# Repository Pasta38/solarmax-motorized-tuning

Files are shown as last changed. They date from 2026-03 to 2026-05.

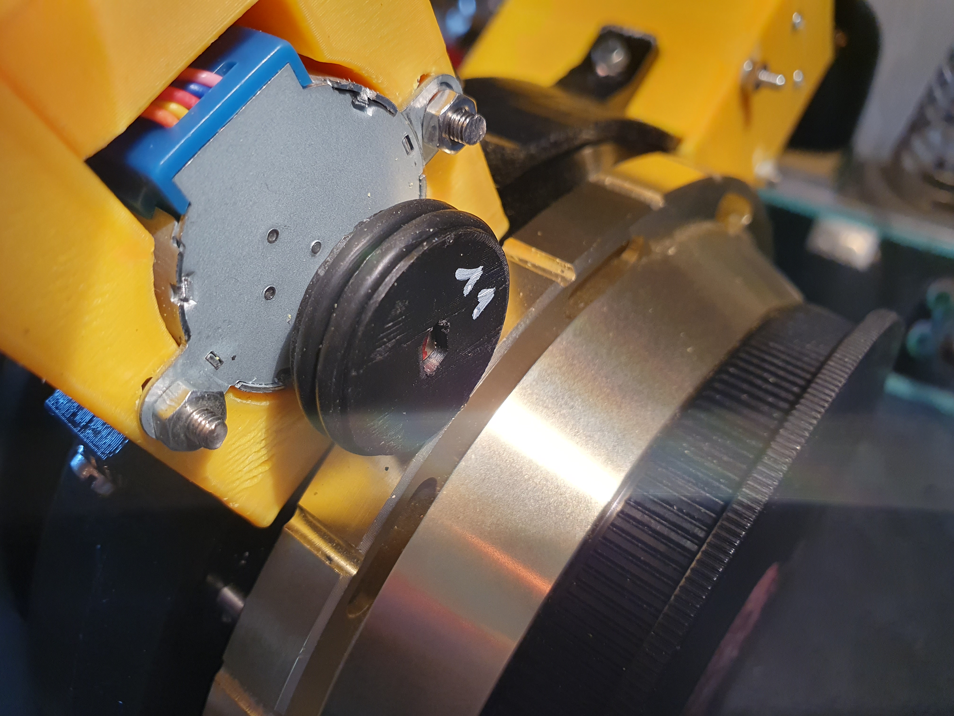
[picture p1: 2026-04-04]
docs/photos/Mecanique/SudNord_Ver1-2.jpg

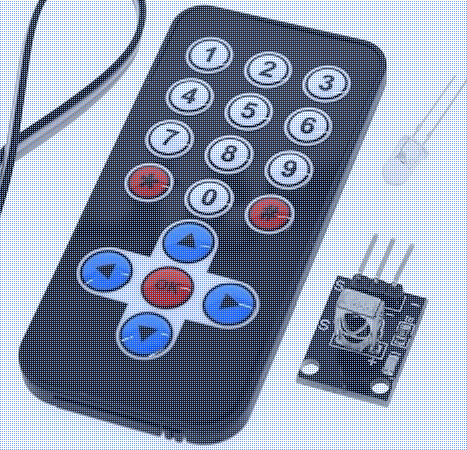
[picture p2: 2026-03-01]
docs/photos/Electronique/Telecommande et recepteur IR.png

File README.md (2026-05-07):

# solarmax-motorized-tuning
Motorized tuning system for Solarmax III 90 double stack telescope

# Système de réglage motorisé pour Solarmax III 90 Double Stack

## Présentation

Ce projet propose un **système de motorisation des réglages** pour une lunette solaire Solarmax III 90 en configuration double stack.

L’objectif est de permettre un réglage **précis, reproductible et confortable** des bagues d’accord, sans manipulation directe sur l’instrument.
Le système est entièrement conçu dans une logique **DIY / open hardware**, avec :

* Électronique basée sur Arduino
* PCB personnalisés
* Pièces mécaniques imprimables en 3D
* Câblage modulaire

Il est particulièrement adapté aux astrophotographes et observateurs solaires souhaitant automatiser leur réglage sans modification permanente de l’instrument.

---

## Fonctionnalités principales

* Commande à distance via télécommande infrarouge
* 4 moteurs indépendants
* Réglage fin et répétable
* Câblage modulaire RJ12
* Boîtier compact
* Pièces 100% imprimables en 3D
* Composants économiques et faciles à trouver

---

## Architecture du système

### Vue d’ensemble

Le système se compose de trois sous-ensembles principaux :

1. Électronique de contrôle
2. Cartes adaptatrices moteurs
3. Ensemble mécanique

---

## Électronique

### Carte principale

Carte conçue avec **KiCad** et fabriquée chez **JLCPCB**.

#### Fonctions

* Support Arduino Nano
* Pilotage de 4 moteurs pas-à-pas
* Réception infrarouge
* Distribution alimentation
* Connectique RJ12 pour moteurs

#### Caractéristiques

* PCB double couche
* Composants traversants (facilité d’assemblage)
* Conception compacte

---

### Composants principaux

| Composant | Rôle |
| --- | --- |
| Arduino Nano | Contrôleur principal |
| 2 × ULN2003AN | Drivers moteurs |
| 2 × 28BYJ-48 5V  | Moteurs pas-à-pas |
| 2 × A4988 | Drivers moteurs |
| 2 × NEMA 17 | Moteurs pas-à-pas |
| Récepteur IR | Interface télécommande |
| Régulateur 5V | 9v vers 5v LM7805 |
| Connecteurs RJ12 | Liaison moteurs |
| JST-XH5 | Connexion côté moteur  |

---

### Cartes adaptatrices RJ12 → JST-XH5

Quatre petites cartes dédiées permettent :

* Conversion RJ12 vers connecteur moteur standard
* Déport des connexions près des moteurs
* Maintenance facilitée

Elles sont volontairement simples pour un assemblage rapide.

---

## Partie mécanique

### Conception

Toutes les pièces mécaniques ont été conçues avec **FreeCAD** et optimisées pour l’impression 3D FDM.

### Éléments fournis

* Boîtier électronique
* Supports moteurs
* Interfaces de fixation sur la lunette (brides)
* Systèmes de maintien des câbles (optionnel)

### Objectifs de conception

* Montage sans modification irréversible de la lunette
* Démontage rapide
* Rigidité suffisante pour réglages fins
* Impression sans supports complexes

---

### Paramètres d’impression recommandés

| Paramètre | Valeur conseillée |
| --- | --- |
| Technologie | FDM |
| Buse | 0.4 mm |
| Hauteur de couche | 0.2 mm |
| Remplissage | 20–30% |
| Matériau | PETG recommandé |

#### Remarques

* PETG pour stabilité thermique
* ABS possible en environnement chaud
* PLA déconseillé en plein soleil

---

## Firmware

Le firmware est conçu pour un **Arduino Nano**.

### Fonctions

* Décodage télécommande infrarouge
* Sélection individuelle des moteurs
* Contrôle pas-à-pas
* Gestion du sens de rotation
* Réglage fin des déplacements

### Dépendances typiques

* IRremote (ou équivalent)
* Librairies stepper Arduino ou implémentation custom

Voir le dossier `/firmware` pour :

* Code source
* Mapping télécommande
* Instructions de compilation

---

## Câblage

### Principe

Chaque moteur est relié via :

Carte principale → RJ12 → Câble → Carte adaptatrice → JST-XH5 → Moteur

### Avantages

* Modularité
* Remplacement rapide
* Longueur de câble adaptable
* Installation propre

---

## Alimentation

### Spécifications

* Tension : 9V DC (pile)
* Courant recommandé : ≥ 2A

---

## Assemblage

### 1. Assemblage électronique

1. Souder les connecteurs sur la carte principale
2. Installer les drivers
3. Ajouter les headers Arduino
4. Flasher le firmware
5. Tester le récepteur IR
6. Tester chaque moteur individuellement

---

### 2. Cartes adaptatrices

1. Souder RJ12 et JST-XH5
2. Vérifier continuité
3. Identifier chaque moteur

---

### 3. Assemblage mécanique

1. Imprimer toutes les pièces STL
2. Monter les moteurs dans leurs supports
3. Installer les supports sur la lunette
4. Monter l’électronique dans le boîtier
5. Installer le câblage

---

## Calibration

Procédure recommandée :

1. Test à vide (sans charge mécanique)
2. Vérification sens de rotation
3. Correction firmware si nécessaire
4. Installation sur la lunette
5. Définition position neutre
6. Tests de réglage fin

---

## Utilisation

1. Mettre sous tension
2. Pointer la télécommande vers le récepteur
3. Sélectionner le moteur
4. Ajuster le réglage

Le mapping des touches est documenté dans le firmware.

---

## Structure du dépôt

```
/hardware
  /kicad-main-board
  /adapter-pcbs

/mechanical
  /freecad
  /stl

/firmware

/docs
  photos
  schémas
  câblage
```

---

## Fabrication

### PCB

* Compatible JLCPCB standard
* 2 couches
* Fichiers Gerber fournis

---

### Impression 3D

Testé sur imprimantes FDM standard.
Aucune contrainte particulière.

---

## Améliorations possibles

* Contrôle Bluetooth ou WiFi
* Intégration ASCOM / INDI
* Écran OLED
* Positions mémorisées
* Drivers silencieux (TMC)
* Version autonome sur batterie
* Capteurs de position

---

## Licence

Licence MIT (modifiable selon votre choix).

---

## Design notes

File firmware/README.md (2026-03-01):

pilotage de 4 moteurs sur Nano avec une telecommande IR

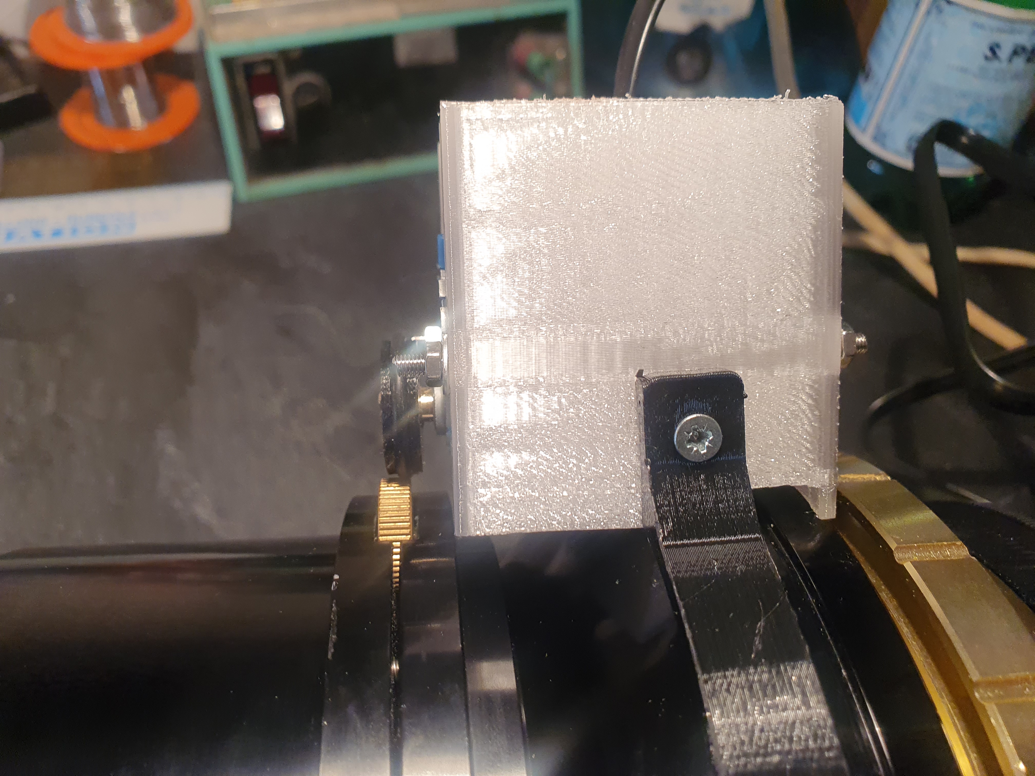
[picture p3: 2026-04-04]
docs/photos/Mecanique/Prototype 2.jpg

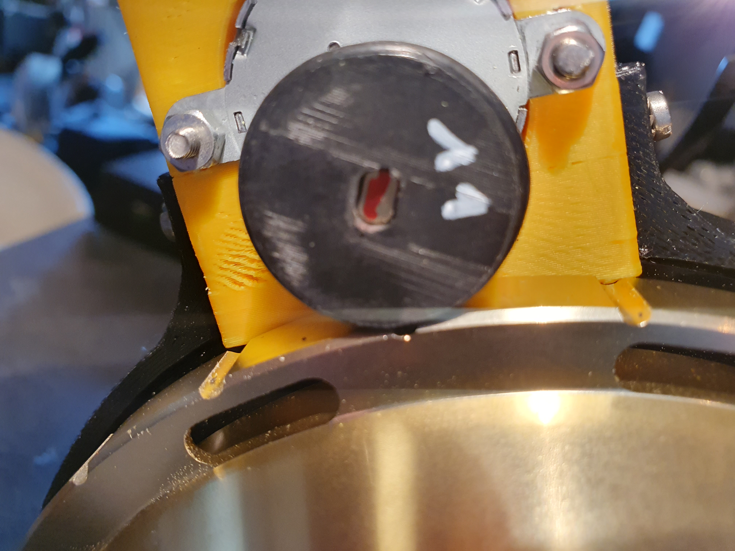
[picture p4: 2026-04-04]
docs/photos/Mecanique/SudNord_Ver1-3.jpg

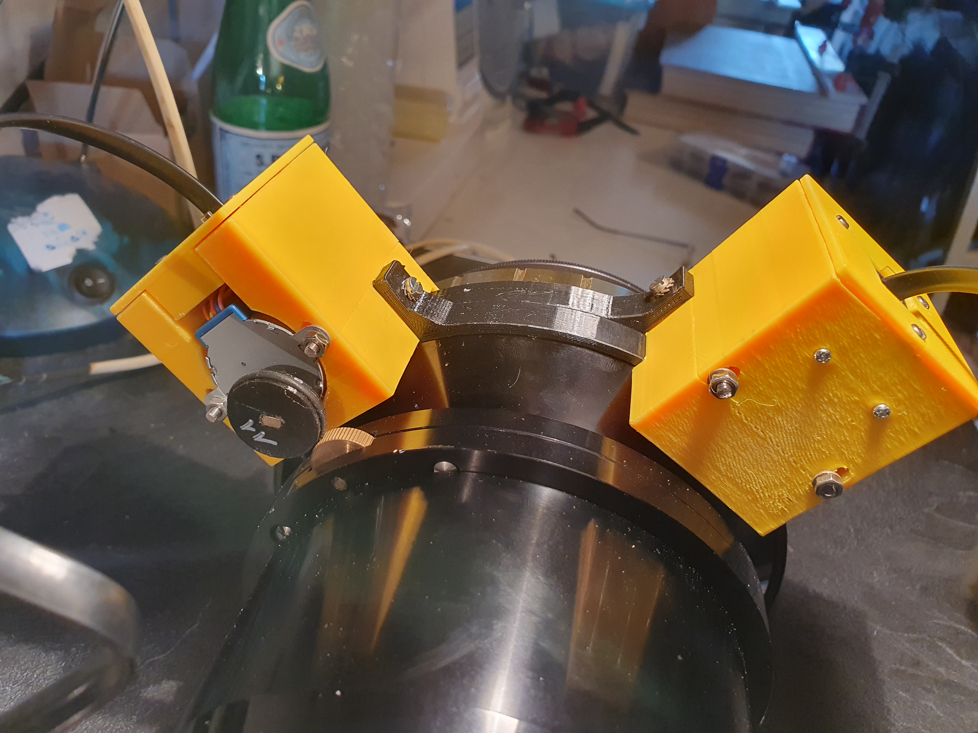
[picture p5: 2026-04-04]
docs/photos/Mecanique/SudNord_Ver1-4.jpg

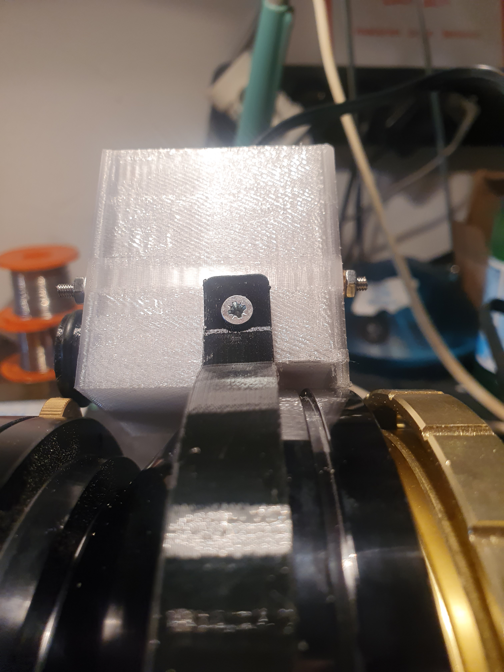
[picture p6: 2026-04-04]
docs/photos/Mecanique/Prototype 3.jpg

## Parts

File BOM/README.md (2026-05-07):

BOM (Bill Of Material) Liste des composants



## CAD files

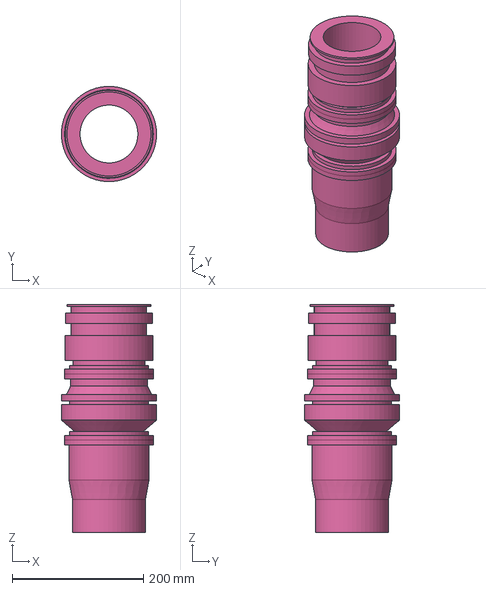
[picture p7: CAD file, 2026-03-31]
mechanical/freecad/Support Moteur & Brides/Coronado-SolamrMaxIII_Model.step
144.9 x 144.9 x 347.0 mm

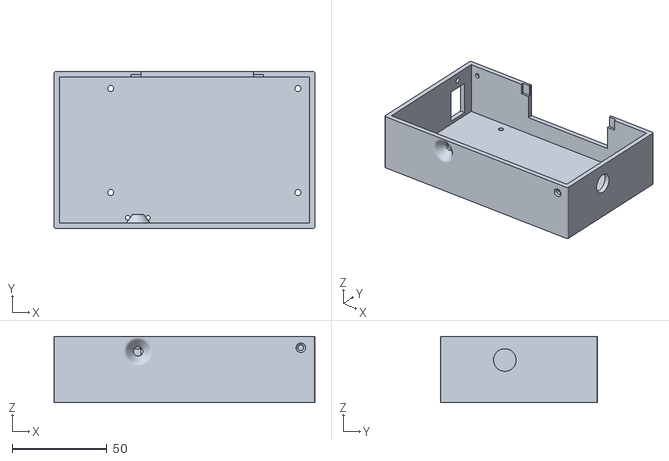
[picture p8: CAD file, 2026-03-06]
mechanical/stl/Boitier/SolarFoc1_box5.stl
138.0 x 83.0 x 35.0

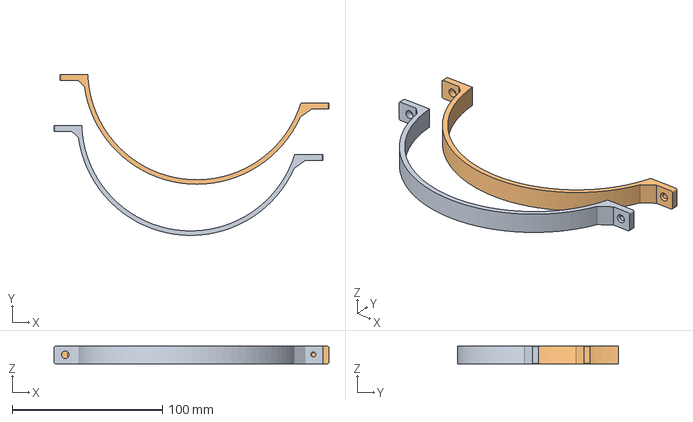
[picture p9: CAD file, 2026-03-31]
mechanical/stl/Brides/demiBrideS3.3mf
183.0 x 107.0 x 11.8 mm
demiBrideS3.stl x 2

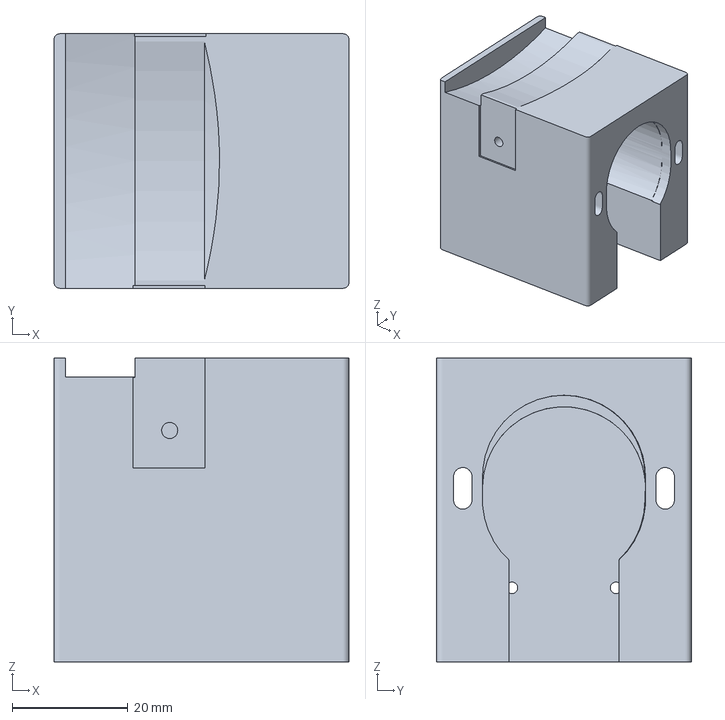
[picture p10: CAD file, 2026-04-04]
mechanical/stl/Supports_Moteurs/Corps3-sud.3mf
51.0 x 44.0 x 52.5 mm

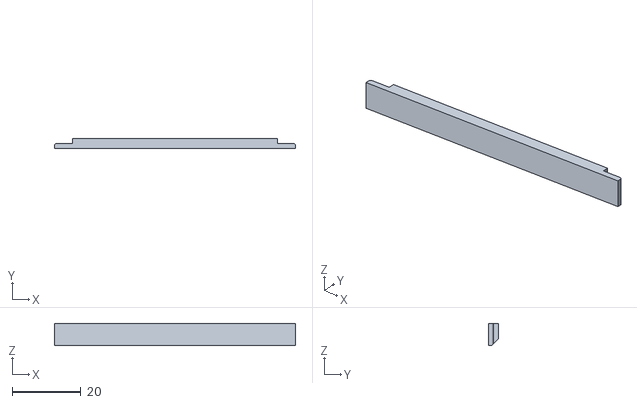
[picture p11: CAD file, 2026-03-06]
mechanical/stl/Boitier/SolarFoc1_Lint5.stl
70.0 x 3.00 x 6.50

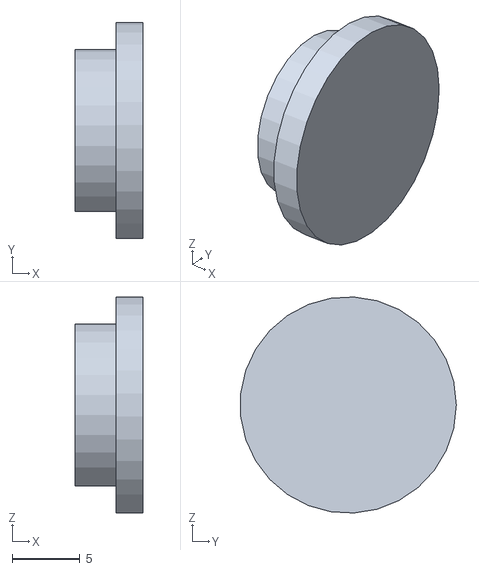
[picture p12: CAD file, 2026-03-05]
mechanical/stl/Boitier/SolarFoc1_SideCov3.stl
5.00 x 16.0 x 16.0

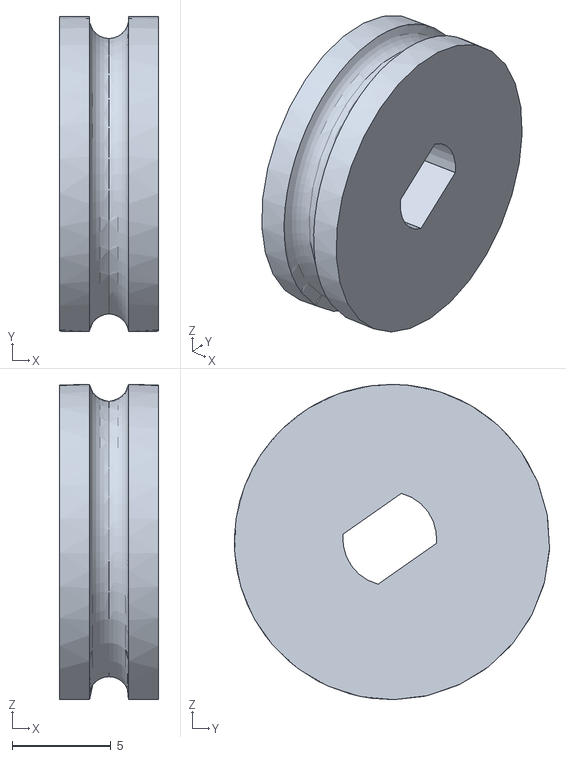
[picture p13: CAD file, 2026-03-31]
mechanical/stl/Supports_Moteurs/Roue.stl
5.00 x 16.0 x 16.0

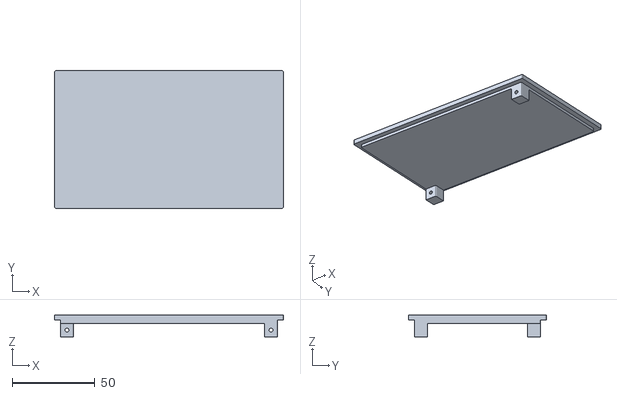
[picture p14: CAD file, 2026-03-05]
mechanical/stl/Boitier/SolarFoc1_TopCov3.stl
138.0 x 83.0 x 13.0

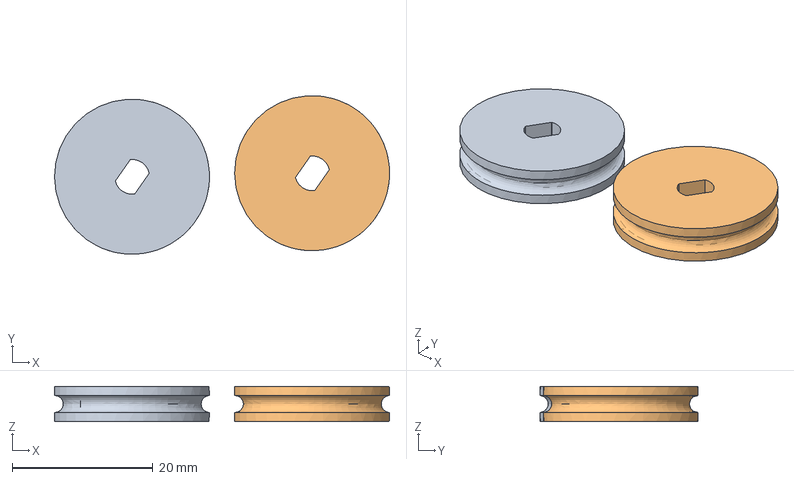
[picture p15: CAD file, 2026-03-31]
mechanical/stl/Supports_Moteurs/Roue_11.3mf
47.6 x 22.5 x 5.00 mm
Roue_11.stl x 2

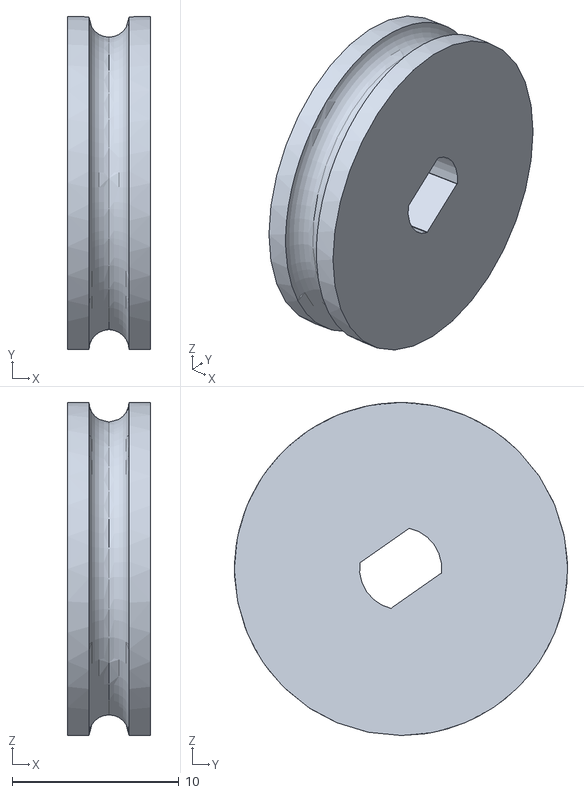
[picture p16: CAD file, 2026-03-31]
mechanical/stl/Supports_Moteurs/Roue_10.stl
5.00 x 20.0 x 20.0

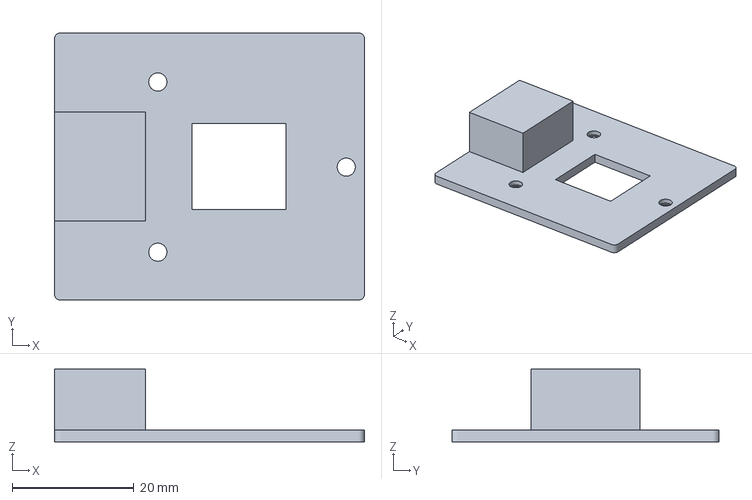
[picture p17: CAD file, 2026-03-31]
mechanical/stl/Supports_Moteurs/Top3.3mf
51.0 x 44.0 x 12.0 mm

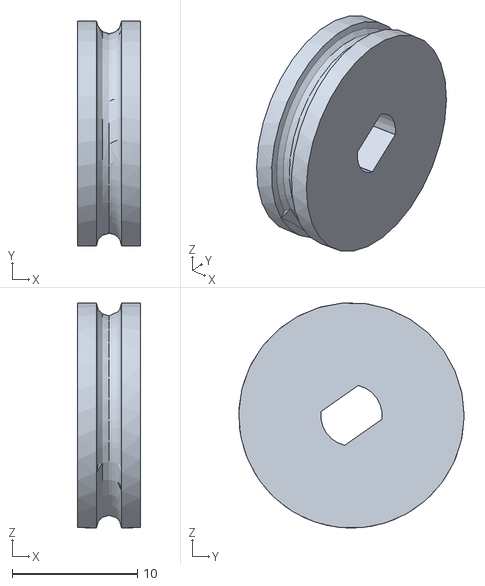
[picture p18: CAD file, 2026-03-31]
mechanical/stl/Supports_Moteurs/Roue_9.stl
5.00 x 18.0 x 18.0

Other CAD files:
mechanical/stl/Supports_Moteurs/Corps1-nord.3mf
mechanical/stl/Brides/demiBrideS3.stl
mechanical/stl/Supports_Moteurs/Corps1-nord.stl
mechanical/stl/Supports_Moteurs/Corps3-sud.stl
mechanical/stl/Supports_Moteurs/Roue_11.stl
mechanical/stl/Supports_Moteurs/Top3.stl

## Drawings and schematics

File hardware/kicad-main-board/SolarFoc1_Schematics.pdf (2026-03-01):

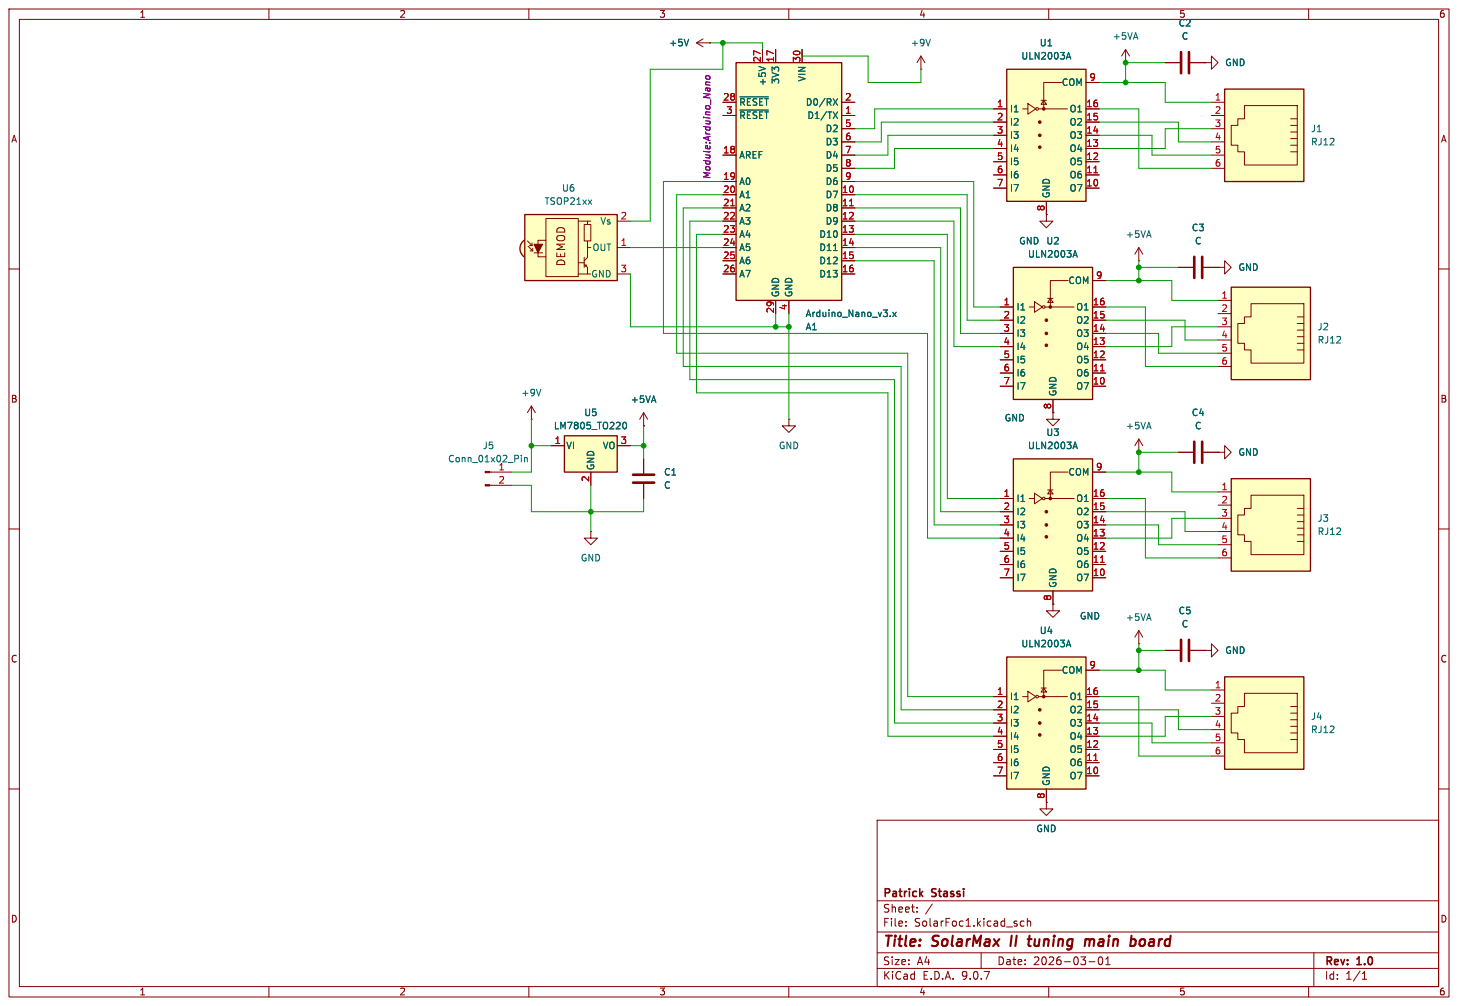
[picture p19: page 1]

Id: 1/1 Title: SolarMax II tuning main board

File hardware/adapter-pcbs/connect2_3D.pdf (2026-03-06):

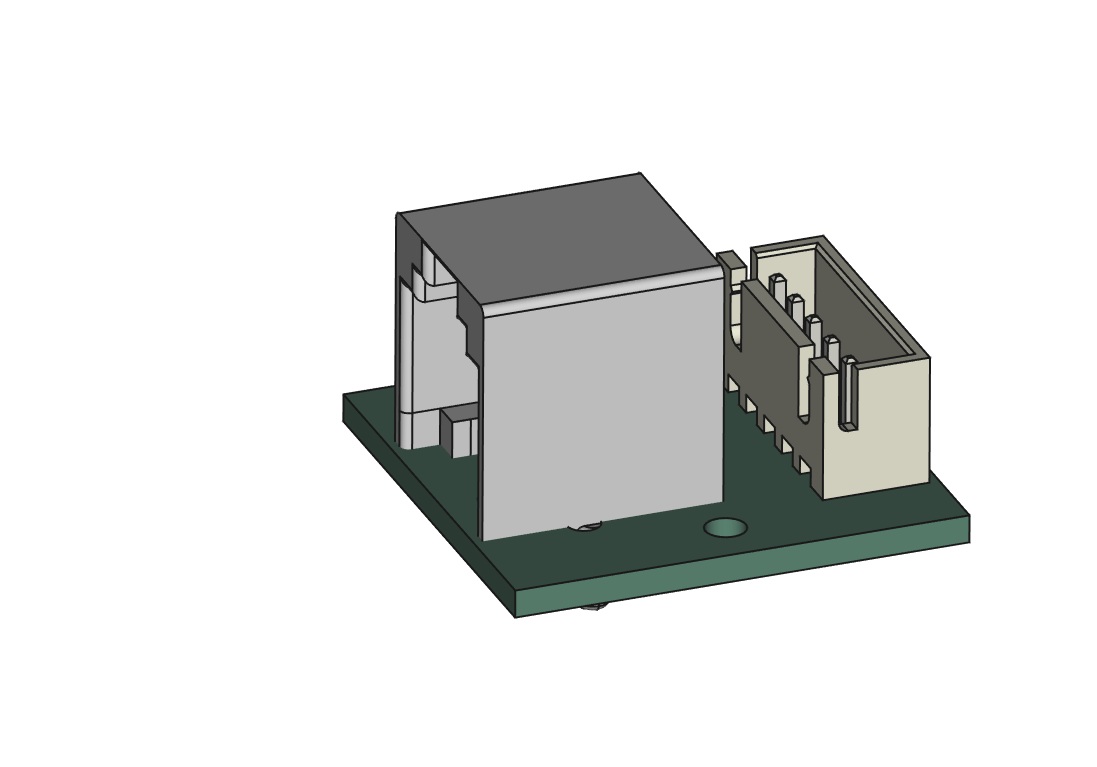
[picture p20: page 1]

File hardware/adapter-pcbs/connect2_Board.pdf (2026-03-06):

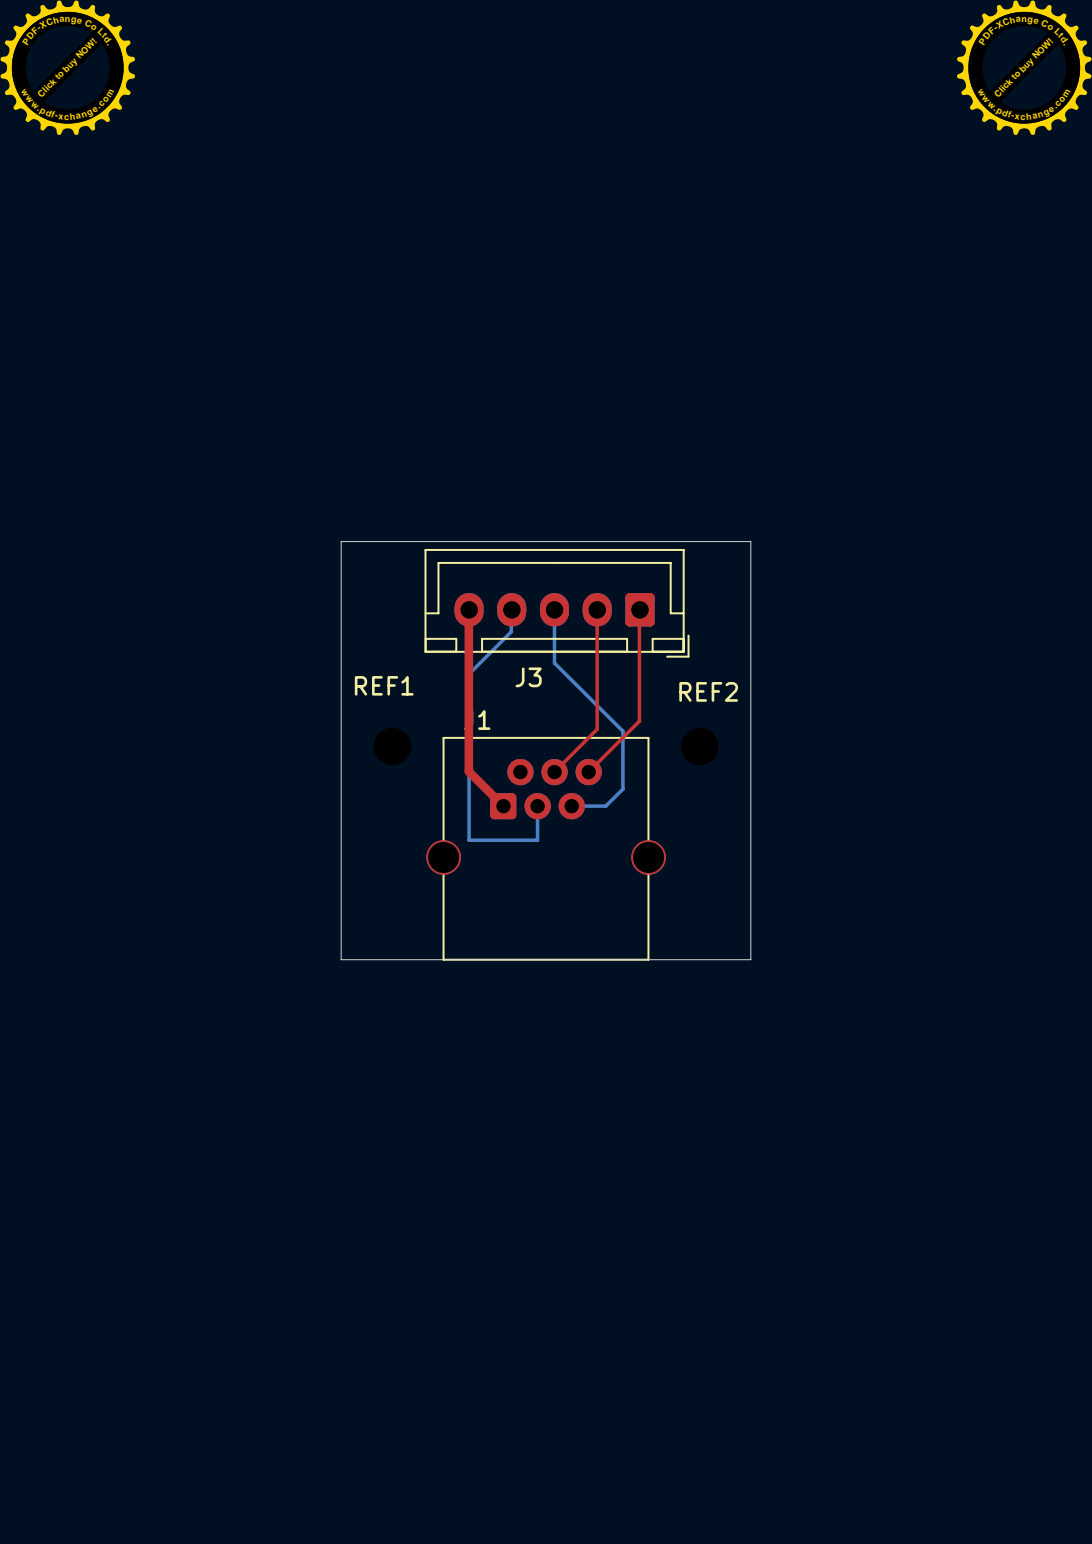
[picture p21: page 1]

PDF-XChange Co Ltd.

Click to buy NOW!

www.pdf-xchange.com

www.pdf-xchange.com (https://www.pdf-xchange.com/buy-now)

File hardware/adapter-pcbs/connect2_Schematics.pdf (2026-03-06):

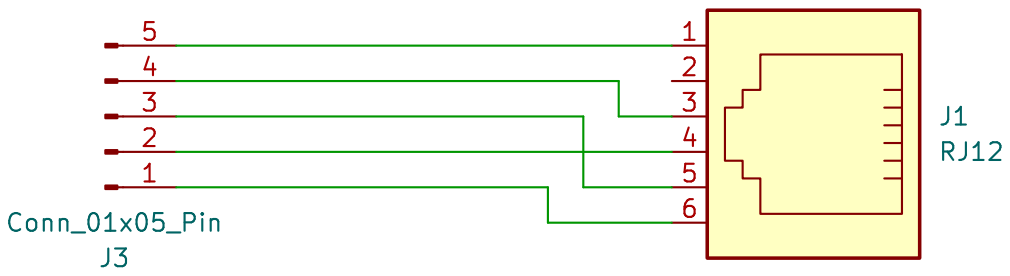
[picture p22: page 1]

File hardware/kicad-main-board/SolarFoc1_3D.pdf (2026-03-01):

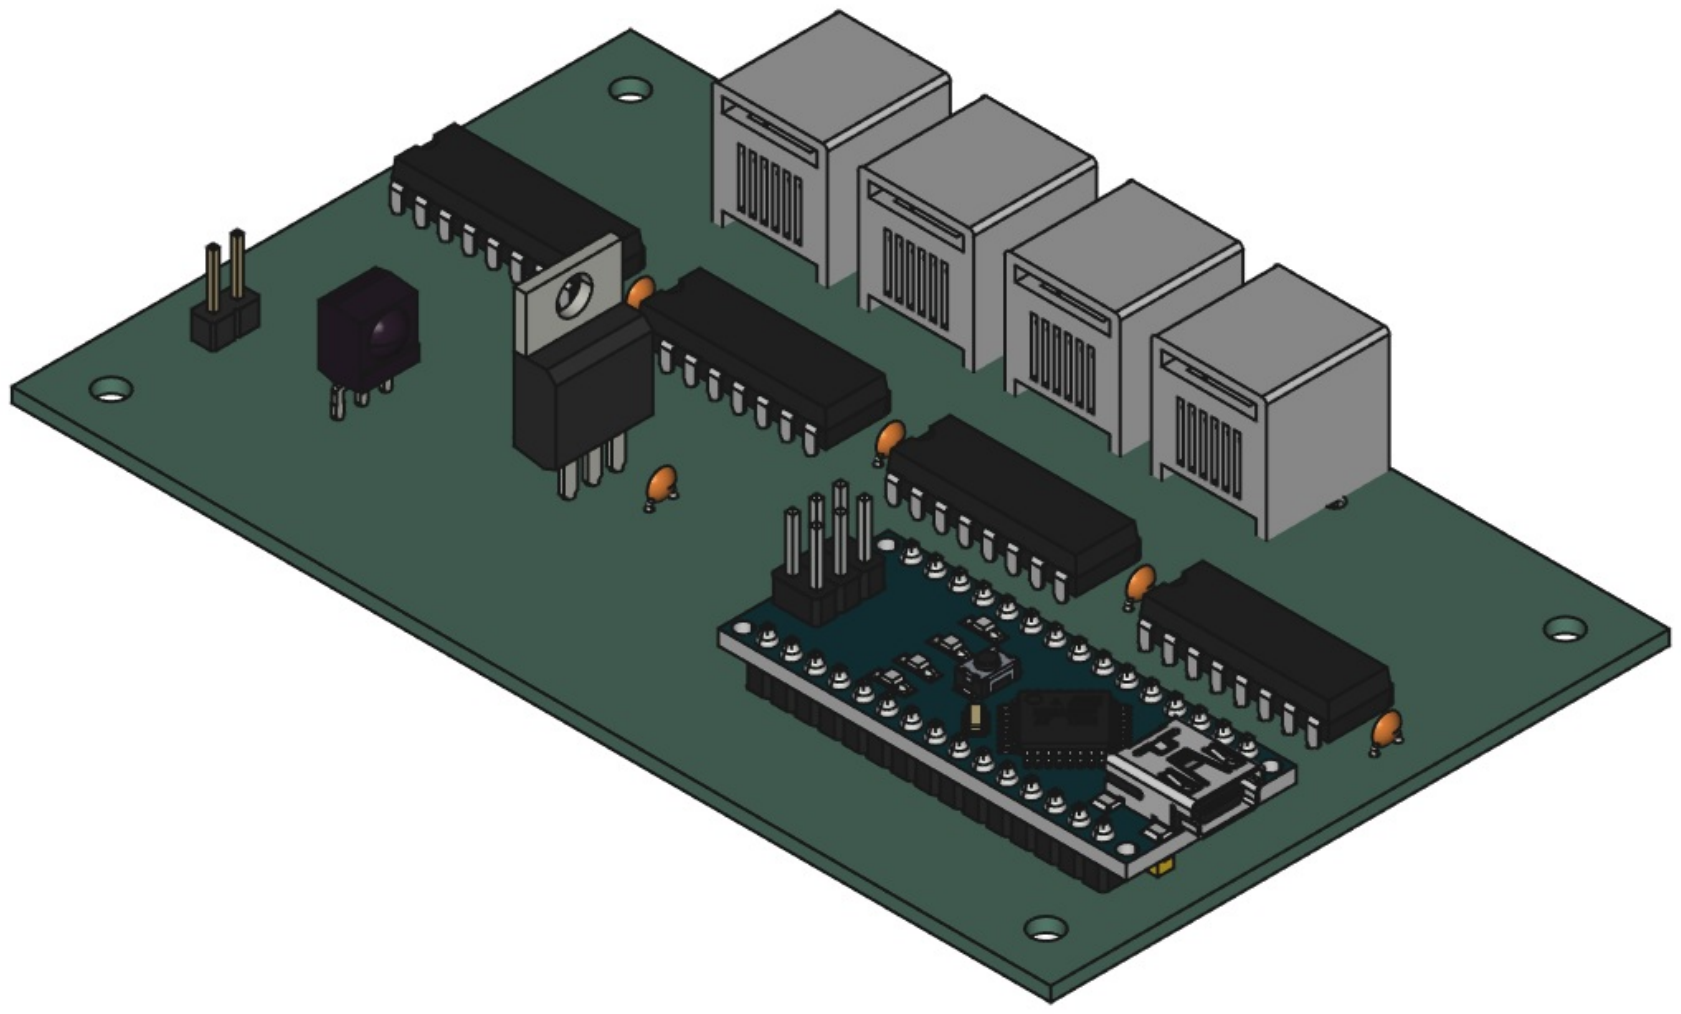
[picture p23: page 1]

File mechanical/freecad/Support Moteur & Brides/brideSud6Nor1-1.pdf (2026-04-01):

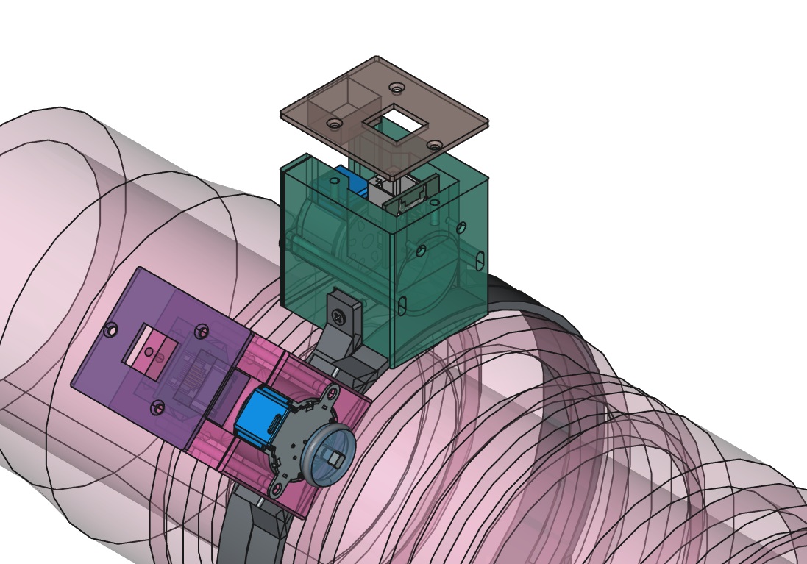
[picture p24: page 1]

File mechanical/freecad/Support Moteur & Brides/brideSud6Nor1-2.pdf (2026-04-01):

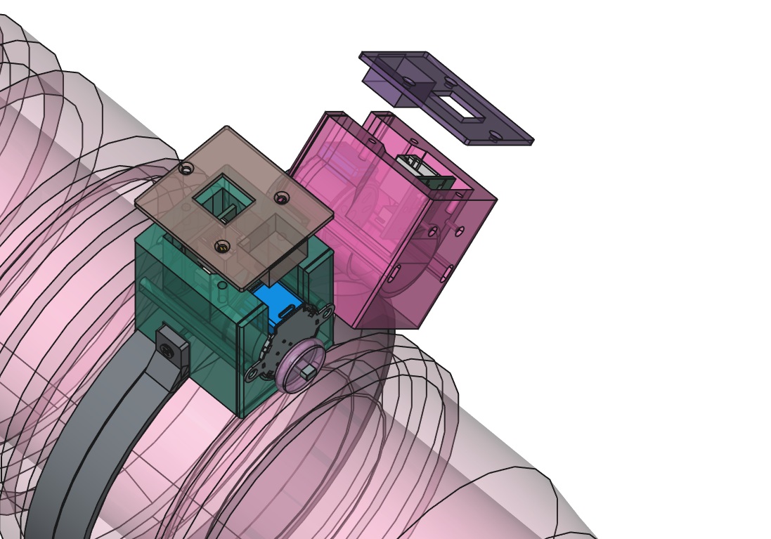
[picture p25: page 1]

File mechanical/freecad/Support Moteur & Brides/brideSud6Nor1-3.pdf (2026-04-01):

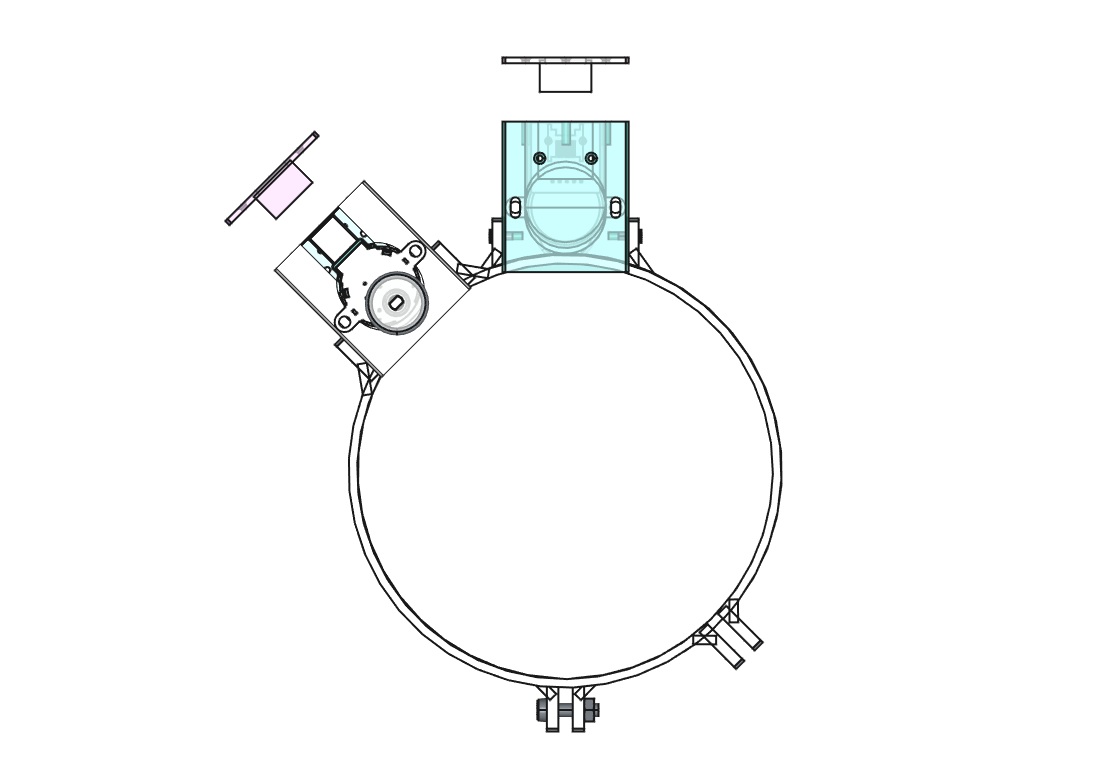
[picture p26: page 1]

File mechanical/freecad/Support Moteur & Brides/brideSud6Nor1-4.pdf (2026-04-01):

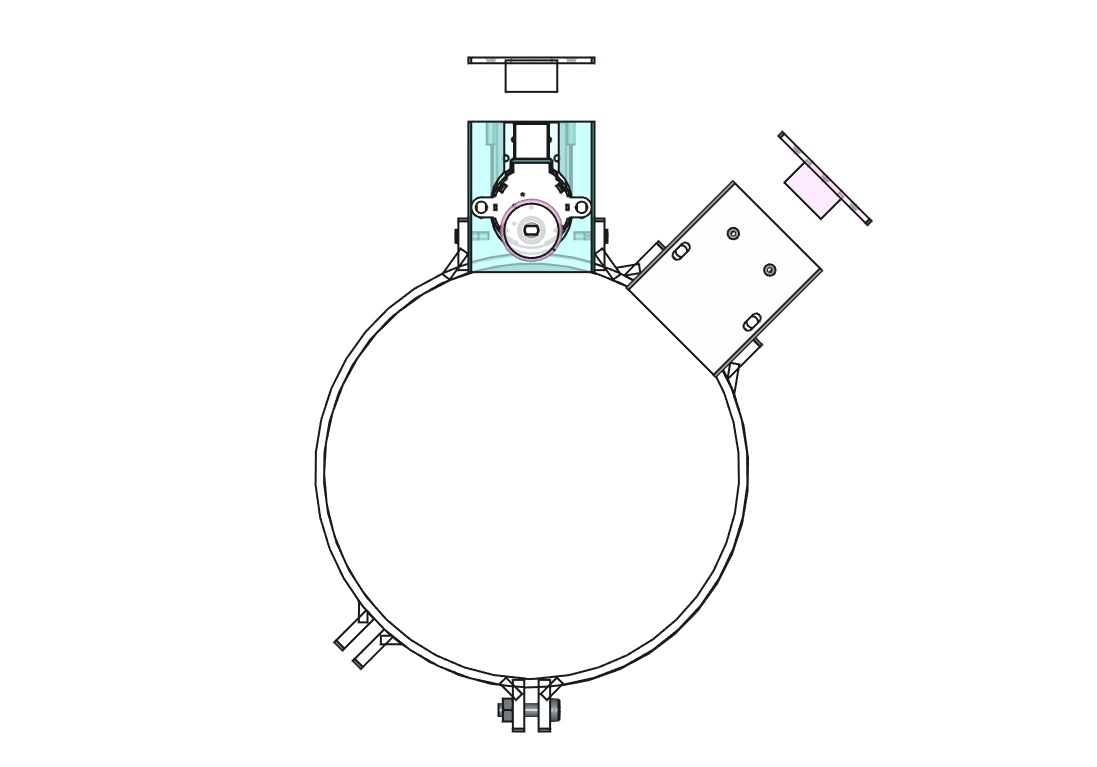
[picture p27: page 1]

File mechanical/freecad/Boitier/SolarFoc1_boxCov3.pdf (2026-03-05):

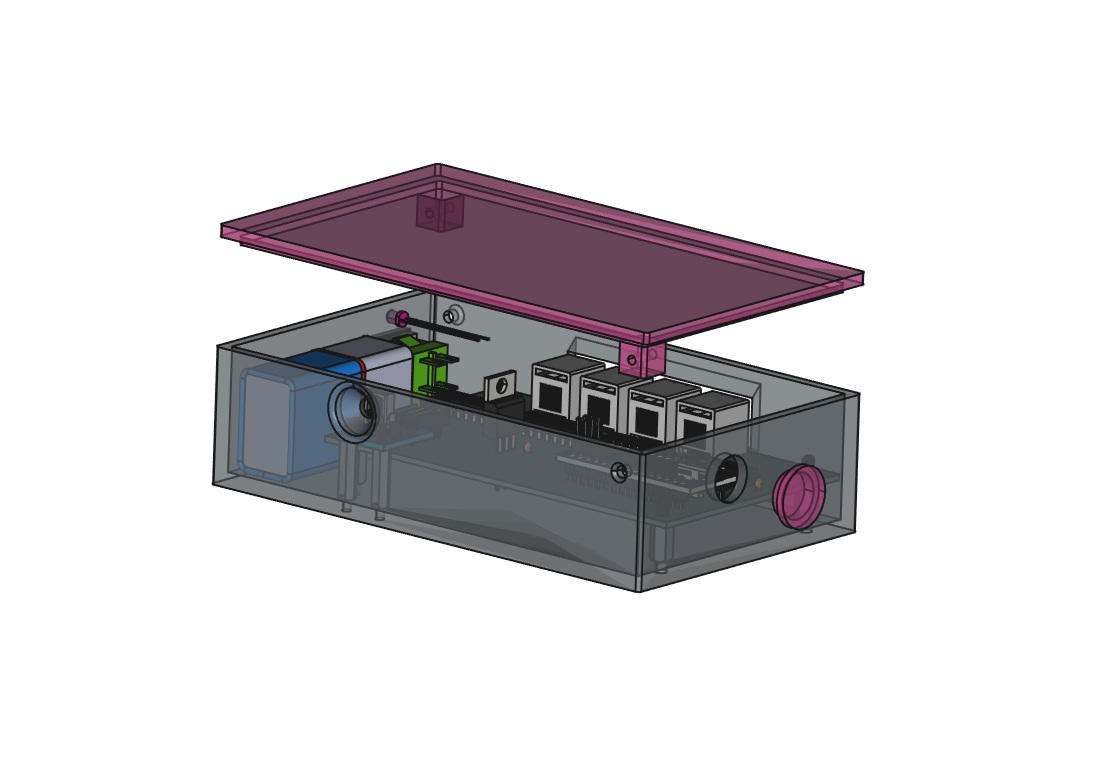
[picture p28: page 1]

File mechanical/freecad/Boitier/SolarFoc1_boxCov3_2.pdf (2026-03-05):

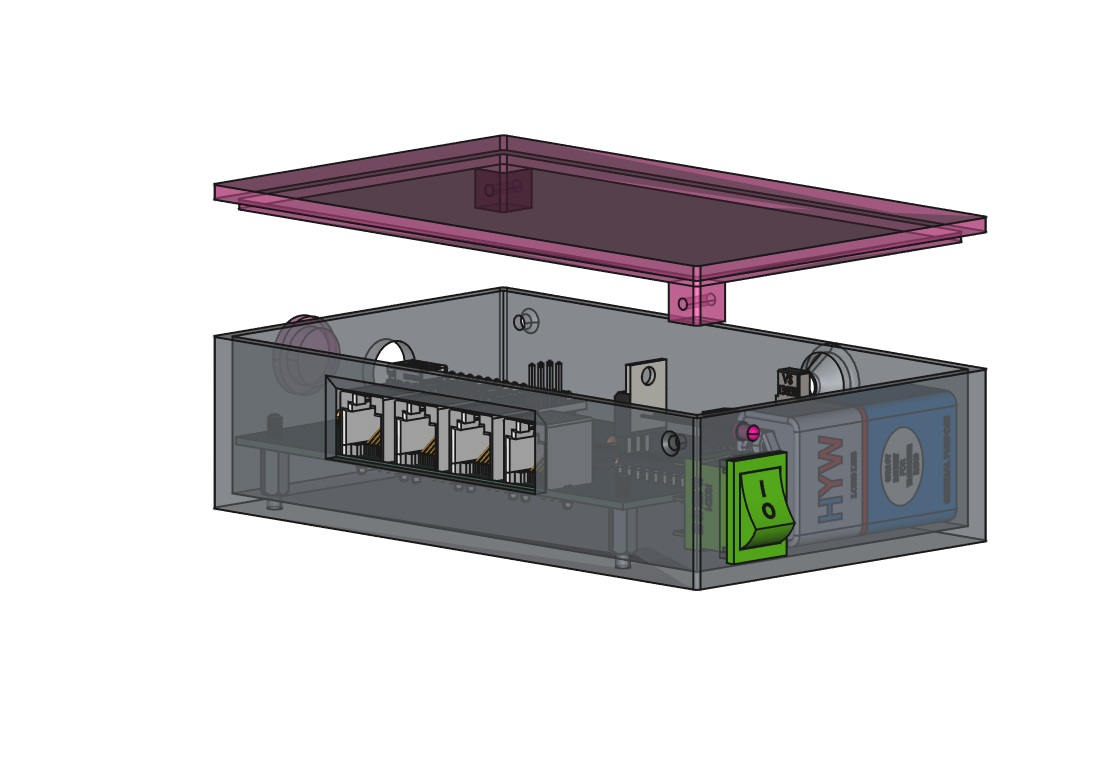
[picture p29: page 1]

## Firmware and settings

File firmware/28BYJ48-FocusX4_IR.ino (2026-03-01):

#include <Stepper.h>
// pilotage de 4 moteurs sur Nano avec une telecommande IR

#include "IRremote.hpp"

#define IR_RECEIVE_PIN 19

int stepsPerRevolution = 2048;


Stepper myStepper1(stepsPerRevolution, 2, 4, 3, 5);
Stepper myStepper2(stepsPerRevolution, 6, 8, 7, 9);
Stepper myStepper3(stepsPerRevolution, 10, 12, 11, 14);
Stepper myStepper4(stepsPerRevolution, 15, 17, 16, 18);

void setup() {
  myStepper1.setSpeed(5);
  myStepper2.setSpeed(5);
  myStepper3.setSpeed(5);
  myStepper4.setSpeed(5);
  
  IrReceiver.begin(IR_RECEIVE_PIN, ENABLE_LED_FEEDBACK);
  // initialize the serial port pour tests :
  Serial.begin(9600);
}

void loop() {
  if (IrReceiver.decode()) {
    uint16_t command = IrReceiver.decodedIRData.command;
    Serial.println(command);    // pour tests
    if (command == 69) {        // 1
      myStepper1.step(5);
    } else if (command == 71) { // 3
      myStepper1.step(-5);
    } else if (command == 68) { // 4
      myStepper2.step(5);
    } else if (command == 67) { // 6
      myStepper2.step(-5);    
    } else if (command == 7) {  // 7
      myStepper3.step(5);    
    } else if (command == 9) {  // 9
      myStepper3.step(-5);    
    } else if (command == 22) { // *
      myStepper4.step(5);    
    } else if (command == 13) { // #
      myStepper4.step(-5);    
    }
    
    IrReceiver.resume();
  }
}
